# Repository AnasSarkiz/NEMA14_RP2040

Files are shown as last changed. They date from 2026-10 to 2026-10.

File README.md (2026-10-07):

# NEMA14_RP2040

Separate RP2040 hardware prototype derived from the CH32X035 NEMA14 controller. This project has its own source, routing and package identity; it does not replace the CH32 project.

[GitHub](https://github.com/AnasSarkiz/NEMA14_RP2040) · [tscircuit](https://tscircuit.com/AnasSarkiz/NEMA14_RP2040)

For STEPperONLINE **14HM11-0404S**: 0.9° bipolar motor, 0.40 A/phase, 25 Ω windings, 35.2 mm maximum body width. The 35 × 35 mm four-layer PCB has four 3.2 mm holes at 26 mm pitch. The manufacturer specifies those dimensions for **front** mounting only; rear attachment uses an adapter and remains physically unverified.

- Two top-side USB-C receptacles, openings flush at opposite board edges: CH224K PD sink requests 15 V, separate USB 2.0 data connection to RP2040.
- RP2040 QFN56, 2 MB GD25Q16EEIGR external QSPI flash, 12 MHz ABM8-272-T3 crystal, 27 Ω USB resistors, all supply bypasses and 1.1 V core-regulator reservoirs.
- AP63203WU-7 3.3 V buck, diode-OR inputs from PD and data VBUS. Motor rail is supplied only by the PD port; data VBUS cannot supply the motor.
- A4988 chopper driver: 1/16 stepping, nominal peak phase-current setting 0.351 A. This setting uses 39k/10k VREF and 0.24 Ω sense resistors; 1% divider/sense resistors and the regulator tolerance must be included in the production current review.
- Top-side component assembly; top/inner2/bottom routing, inner1 ground plane and through-vias. The four-layer PCB costs more than the CH32 two-layer version. SWD/reset solder pads, BOOTSEL solder pads (short to GND while resetting), four motor wire solder holes. These pads avoid connector/button cost.

Motor connection: black A+, green A−, red B+, blue B−. Firmware must keep ENABLE_N high and SLEEP low until the negotiated supply is verified. Data-VBUS sensing is required to disconnect the USB device pull-up when the host cable is absent.

```sh
npm ci --legacy-peer-deps
npm run typecheck
npm run source:check
npm run autoroute       # diagnostic copper saved separately
npm run build           # render/check delivery copper, without rerouting
npm run export
npm run shorts
```

See [routing](docs/routing.md), [electrical review](docs/electrical.md), and [firmware interface](docs/firmware-interface.md). **Hardware prototype, not a fabrication release.** No firmware or bench-tested USB, PD, current or thermal behavior is included.

Saved validation: 0 DRC errors, 48 nets connected and no Gerber shorts detected across all four copper layers. Power/ground pin metadata and passive connector/crystal classifications are explicit; current DRC reports zero warnings. [BOM](artifacts/bom.csv), [Gerbers](artifacts/nema14-gerbers.zip) and [top preview](artifacts/pcb-top.png) are included. Exact passive purchasing identities, assembly rotations and the inductor footprint still require assembly review.

## Supplier models and A4 schematics

[Printable A4 schematic](artifacts/schematic-a4.pdf): 13 numbered landscape sheets with chip-purpose notes and every numbered physical pin. All **61/61 fitted components** use exact JLCPCB imports with native land patterns and OBJ/STEP models. Motor/debug/boot connections are bare PCB pads. See [supplier CAD details](docs/supplier-cad.md) and [the import report](artifacts/jlcpcb-import-report.json).

## USB and final validation

[USB programming procedure](docs/usb-programming.md) · [Validation details](docs/validation.md) · [Browser schematic analysis](artifacts/validation/schematic-analysis-ui.png). Both board variants support boot-mode entry through their Data USB-C port; flashing still requires assembled-hardware validation. Current software checks report zero DRC errors/warnings, zero schematic-placement findings and no Gerber shorts. Application firmware remains a separate task.

The public main entry point is `index.circuit.tsx`, which exports the board from `src/board.tsx`. `index.circuit.json` is the checked saved layout; publication refreshes it from `artifacts/board.circuit.json` and includes both JSON files. `tscircuit.config.json` selects the root source entry and saved-layout preview.

Publication uses the CLI build-output option: `tsci push index.circuit.tsx --include-dist`. Before uploading, the script runs `tsci build index.circuit.json` and verifies that `dist/index/circuit.json` equals the checked saved routing.

## Copper and electrical review

The [electrical review](docs/electrical.md) records power-trace widening, filled grounds, the corrected 100 kΩ/10 kΩ motor-voltage divider, copper-thickness requirements, and remaining prototype tests. Run `npm run check:copper` for the actual saved-segment audit. The [machine-readable report](artifacts/trace-width-review.json) distinguishes isolated tracks from parallel ground-plane paths; software checks do not certify hardware operation.

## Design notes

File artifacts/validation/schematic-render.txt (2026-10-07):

> NEMA14_RP2040@1.0.8 render
> bun scripts/render.ts --schematic-only

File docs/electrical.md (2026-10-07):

# Electrical design review

RP2040 is not a drop-in CH32 replacement. All six IOVDD pins, USB_VDD, ADC_AVDD and VREG_IN use 3.3 V. VREG_OUT and both DVDD pins use the separate internal 1.1 V rail. Each IOVDD/DVDD/USB/ADC supply has a 100 nF bypass; VREG input/output each have 1 μF. TESTEN and the exposed pad are grounded. RUN has a 10k pull-up and a debug reset pad.

12 MHz ABM8-272-T3 has 10 pF specified load; two 15 pF capacitors assume about 2.5 pF parasitic load. A 1k XOUT series damping resistor is included. Verify clock startup and drive level on hardware. GD25Q16EEIGR is 16 Mbit/2 MB, 3.3 V USON8. Flash CS has 10k pull-up; both IO2/IO3 are wired to RP2040 for quad mode.

AP63203WU-7 pin map checked against DS41326 Rev 3-2: FB1, EN2, VIN3, GND4, SW5, BST6. Fixed 3.3 V output, 3.8–32 V input, 1.1 MHz. Manufacturer table 2 specifies 3.9 μH, 10 μF input, two 22 μF output and 100 nF bootstrap. This prototype uses a 4.7 μH SRN4018-4R7M, a nearby standard value reducing ripple; verify stability and load-step behavior. FB senses the output directly. Input ceramic must be rated ≥35 V; bootstrap ≥25 V; output ceramics ≥10 V and retain sufficient capacitance after bias. Inductor saturation/ripple-current and exact footprint require purchasing review. Do not populate an adjustable AP63200 in this footprint without changing the feedback network.

Diode ORing keeps PD voltage out of host VBUS. Actual 5 V USB minimum, Schottky drop and buck dropout must be verified. CH224K supplies motor VBUS only; fallback 5 V cannot run the A4988. PG and VM ADC voltage gate firmware enable. 15 V is requested, not guaranteed with every charger/cable.

A4988 VREF = 3.3 × 10/(39+10) = 0.6735 V; Itrip = VREF/(8 × 0.24) = 0.3508 A. The native 0.24 Ω, 1%, 125 mW resistors dissipate about 29.5 mW nominally. A deliberately expanded 3.465 V rail budget, 1% resistor bounds and a provisional 5% driver allowance estimate 0.3969 A. This is an engineering budget, not a qualified maximum: the actual driver accuracy, ground bounce and sense-track resistance must be measured. The SMF18A clamp still requires regenerative-energy testing.

Only exposed-pad ground vias may sit inside component pads; ordinary vias must clear pads. Component assembly is on top; PCB uses four copper layers: top / inner1 ground / inner2 signals / bottom. Ground is filled on all layers, with inner1 reserved from signal routing. USB is full-speed 12 Mbit/s: matched short pair and continuous ground reference require layout review beyond a generic DRC/short test. No controlled-impedance or EMC compliance claim is made.

## Copper review, 2026-10-07

The checked saved layout, rather than nominal JSX settings, was reviewed. Power/motor tracks were widened only when exact imported pad, via and foreign-track geometry retained at least 0.15 mm clearance. Their centerlines were retained. `artifacts/power-copper-adjustments.json` records each width change; `supplier-routing-adjustments.json` replays the complete result from the saved SES import. Ground pours have 0.20 mm clearance, 0.35 mm edge margin, and no unconnected islands. Components remain top-side assembled.

| Copper | Actual saved width / review |
| --- | --- |
| Motor outputs / sense | About 0.28–0.45 mm, including package escapes; screened at 0.40 A peak |
| PD motor supply | 0.30–0.60 mm; 0.75 A input budget, with a verified single-bridge RP2040 branch screened at 0.40 A |
| Logic supply / switching node | Widened where possible; package escapes remain as small as 0.16 mm; 0.15 A rail / 0.20 A switching budget |
| Ground | 0.16–0.45 mm tracks plus filled ground copper; parallel plane paths must be considered, rather than assuming the entire motor return flows down every ground stub |
| USB / other signals | 0.16 mm; width alone does not establish differential impedance or signal integrity |

Copper screening requires **at least 35 μm finished external copper and 17.5 μm internal copper** where applicable, on 1.6 mm FR-4, with at least 20 μm via barrel plating. These are fabrication requirements, not measurements of a manufactured PCB. IPC-2221 equations use k=0.048 externally and 0.024 internally, with a 30 °C rise screening limit. The report includes each actual segment, layer, current budget and temperature estimate. This approximate method does not model enclosure/motor heating, neck heat spreading, switching pulses, vias or ground-plane current sharing.

The largest isolated non-ground trace estimate is 25.2 °C at its assigned budget. Ground traces covered by the same-net pour are explicitly reported as parallel paths; their isolated-track estimate is not a prediction of actual plane temperature. Ground current sharing and regulator/driver temperatures remain bench checks.

## Voltage sensing correction

R_VM_H/R_VM_L is now **100 kΩ/10 kΩ**, replacing 100 kΩ/22 kΩ. It produces 1.364 V at 15 V; the worst resistor-tolerance value is 3.240 V at a 35 V review envelope. The old divider produced 3.606 V at only 20 V, before tolerance, so motor regeneration could overstress the ADC input. This change reuses JLCPCB C25804 and its unchanged native footprint. **Firmware must multiply VM_SENSE voltage by 11**, with calibration as needed. The 35 V arithmetic envelope is not approval to operate the motor bus at 35 V; the intended supply remains 15 V. Rails, TVS energy and component ratings require transient testing.

## Operation review and remaining tests

CH224K requests 15 V with CFG1/2/3 = 0/1/1; PG is active low. A supply must advertise the requested PDO. Driver ENABLE_N has a pull-up, SLEEP has a pull-down, and firmware must keep the bridge disabled until PG and measured VM are valid. Diode ORing separates host VBUS from PD while permitting logic-only USB power. USB/data ground is shared with motor power.

USB programming entry is wired: WCH ROM ISP through PC17/D+ at cold power-up on CH32; RP2040 ROM USB boot through the flash-CS boot jumper and RUN/reset. This has not been demonstrated on physical hardware. USB routes were checked for continuity and shorts, but were not impedance-qualified or accepted as a length-matched differential pair. Reported per-net copper totals contain connector/ESD branches and must not be interpreted as pair skew. Host-only, PD-only and simultaneous-cable tests, both Type-C orientations, repeated enumeration and actual flashing are required.

At first bring-up, keep the motor disconnected, power through a current-limited source, check all rails and confirm disabled outputs. Then verify 15 V PD negotiation/fallback behavior and absence of host backfeed. Measure 3.3 V ripple and load-step response (plus RP2040 1.1 V and crystal startup), flash over USB, measure both phase currents and sense offsets, and exercise stalled/accelerating/stopping motor cases while watching VM overshoot and driver/regulator temperatures. Test at the intended motor/enclosure temperature. The CH32 linear regulator dissipates roughly (14.6−3.3)×I_logic, or about 0.34 W at 30 mA; the 100 mA part rating alone is not a thermal guarantee. The RP2040 buck's switching/input loop and feedback placement require ripple/stability validation.

No motor-control firmware is present. Rear mounting remains unverified because the motor drawing dimensions only the front face. Manufacturer-level A4988 accuracy, CH224K/HT7533 electrical limits and component transient ratings remain purchasing/release checks; direct manufacturer document retrieval was blocked in this environment. Existing pin/reference and supplier evidence is recorded in `docs/sources.md`. **Manufacturing release remains blocked.**

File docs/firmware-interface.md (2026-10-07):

# RP2040 firmware contract

Use the Pico SDK RP2040 target with 12 MHz XOSC and 2 MB flash. Select the generic JEDEC-compatible boot stage for GD25Q16E; do not assume a Winbond-specific quad-enable sequence. Flash boot and UF2 USB ROM boot require hardware validation.

| Function | RP2040 GPIO / physical pin |
| --- | --- |
| STEP | GPIO6 / 8 |
| DIR | GPIO7 / 9 |
| ENABLE_N | GPIO8 / 11 |
| SLEEP | GPIO9 / 12 |
| PD_GOOD (active low) | GPIO10 / 13 |
| VM_SENSE | ADC2 / GPIO28 / 40 |
| DATA_PRESENT | ADC3 / GPIO29 / 41 |
| SWCLK / SWDIO | 24 / 25 |
| RUN | 26 |
| USB DM / DP | 46 / 47, through 27 Ω resistors |

On reset, pull-ups/pull-downs disable the A4988. Initialize outputs disabled; require PG and measured VM within an accepted 15 V window, then wake the driver and respect its timing before enabling. Monitor supply loss and shut down immediately. Keep USB pull-up disconnected without DATA_PRESENT. Start with low speed; the 24 mH motor inductance and actual torque/load set speed limits.

Full steps: 400/revolution. Configured 1/16 microsteps: 6400/revolution. No USB protocol/application firmware is implemented.

J_DEBUG bottom-to-top in the top PCB view: 3V3, GND, SWCLK, SWDIO, RUN. J_BOOT shorts flash CS to GND through 1 kΩ: hold short while asserting/releasing RUN to enter ROM USB boot. Never leave the short during ordinary flash operation.

For factory ROM USB boot entry, see [USB programming](usb-programming.md). This hardware contract does not supply a motor-control application.

Motor voltage conversion: `VM_V = VM_SENSE_V × 11` for the reviewed 100 kΩ/10 kΩ divider. Update/calibrate firmware accordingly; the former ×(122/22) conversion is obsolete.

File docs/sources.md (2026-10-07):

# Sources and provenance

- Original CH32 project: `AnasSarkiz/NEMA17_Controller`, commit `e19f75e` (independently copied source; original project remains unchanged).
- tscircuit 0.0.2759, CLI 0.1.2258: latest npm releases checked during this change, pinned in lockfile.
- RP2040 Raspberry Pi manufacturer datasheet (cached official supplier copy): `references/RP2040.pdf`. Sections 1.4 and 2.9 establish the numbered pin map, power rails, bypasses, 12 MHz USB boot clock and 27 Ω USB resistors. Original https://datasheets.raspberrypi.com/rp2040/rp2040-datasheet.pdf . Direct manufacturer website access is blocked in this environment; the cached PDF was read.
- Diodes AP63203 DS41326 Rev 3-2, November 2024: `references/AP63203.pdf`, pin descriptions, component table 2 and PCB layout guidance. https://www.diodes.com/assets/Datasheets/AP63200-AP63201-AP63203-AP63205.pdf . Cached manufacturer PDF was read.
- Abracon ABM8-272-T3, drawing 456603 Rev IR November 2023: `references/ABM8-272-T3.pdf`, 12 MHz / 10 pF load / 50 Ω ESR.
- GigaDevice GD25Q16E Rev 1.5: `references/GD25Q16E.pdf`, 16 Mbit, USON 3×2 mm, flash pins and quad-enable behavior. Device-specific boot support requires testing.
- STEPperONLINE 14HM11-0404S: `references/14HM11-0404S.pdf`, retrieved from https://www.omc-stepperonline.com/download/14HM11-0404S.pdf . Electrical ratings and front 26 ±0.2 mm M3 pitch confirmed; rear hole dimensions absent.
- RP2040, AP63203, GD25Q16EEIGR and crystal pad geometry copied from existing cached supplier imports. Numbered pins checked against manufacturer references; assembly/library review is still needed. No generic QFN footprint is substituted for the reduced RP2040 ground pad.

The remaining A4988, CH224K, USB-C and ESD footprints derive from the original project. This is an engineering prototype; exact purchasing identities for passives and the inductor land pattern require final assembly review. No stock check or assembly quote is claimed.

Current fitted parts are genuine JLCPCB imports obtained with `tsci import --jlcpcb --download --use-exact-footprint <C-number>`. `src/jlcpcb-catalog.json` records component-to-part mapping, original import hashes and native OBJ/STEP hashes. No fitted part uses a custom replacement footprint. Earlier KiCad/Eagle references establish pin cross-checks only; they do not define the current supplier land patterns.

Current tools: tscircuit 0.0.2764, CLI 0.1.2261, pinned in the lockfile. WCH evaluation-board reference section 5 documents PC17-high cold-start ROM USB programming. RP2040 and AP63203 manufacturer PDFs used for power/boot/reference checks are cached in the RP2040 project's `references/` directory. The AP63203 PDF is DS41326 Rev 3-2, November 2024, including the fixed-output pin map and PCB layout guidance. Additional direct Allegro/Raspberry Pi document retrieval during this review returned HTTP 403; no new manufacturer qualification is claimed from those failed requests.

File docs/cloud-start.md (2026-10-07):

# Cloud startup

Use the existing `/workspace/NEMA17_Controller` and `/workspace/NEMA14_RP2040` checkouts. Install from lockfiles using `npm ci --legacy-peer-deps`; local scripts supply Bun. `scripts/cloud-install.sh` restores Python routing dependencies in `/workspace/.routing-venv`, verifies locked Git dependency source checksums and Freerouting 2.0.1. Retain TLS/checksum checks.

Run TypeScript, source compilation, saved-board build, native physical connectivity and all-layer Gerber shorts checks. The delivery has 351 trace sections/38 fitted supplier models on CH32 and 519 trace sections/61 fitted models on RP2040; DRC errors and warnings are zero. `npm run build` uses saved copper. `npm run autoroute` writes a separate diagnostic result and does not replace delivery copper.

Use `XDG_CONFIG_HOME=/workspace/.config` for authenticated CLI publication. Reuse configured authentication without printing secrets. Exact JLCPCB imports and OBJ/STEP assets are in `imports/supplier/`; CAD viewers load public GitHub URLs. Native A4 drawings have 9 CH32 and 13 RP2040 pages. The supplier report requires the routing Python environment: `/workspace/.routing-venv/bin/python scripts/report-presentation.py`.

`npm run dev -- --port 5173` starts the saved-board preview. `python3 scripts/schematic-review-ui.py` starts the read-only native A4/CLI findings review UI. Check local HTTP endpoints internally; share the public project links. The official IDE saved-JSON schematic pane is disabled and WebGPU is unavailable here. Restart servers in a fresh task.

Both designs remain unassembled prototypes. Rear-motor fit, physical USB flashing, PD/thermal testing and firmware implementation remain outstanding. The manufacturer drawing gives front mounting only; four 26 mm-pitch holes are for an unverified rear adapter. The CH32 GitHub identity remains AnasSarkiz/NEMA17_Controller because its requested rename returned HTTP 403. Environment draft saving does not activate its configuration; review/save/publish in environment settings. Fresh-task restoration has not been independently tested.

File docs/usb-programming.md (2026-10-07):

# USB programming

1. Short the two bare `J_BOOT` pads to hold flash chip-select low through `R_BOOT` (1 kΩ).
2. While holding the short, connect the computer to **J_DATA** from a fully unpowered board, or momentarily pull `J_DEBUG.RUN` to GND to reset the powered MCU.
3. Release `J_BOOT` after the ROM enters USB boot mode.
4. Copy a firmware UF2 built for this RP2040 board to the ROM's `RPI-RP2` drive, or use `picotool`.

Source: [RP2040 datasheet](https://datasheets.raspberrypi.com/rp2040/rp2040-datasheet.pdf), boot sequence and USB boot documentation. The QSPI flash, 12 MHz crystal, USB 27 Ω series resistors and required rails are present. There is no fitted BOOT button; use the exposed pads. SWD and RUN remain available on `J_DEBUG`.

The **PD port is motor power only**, requesting 15 V. Programming uses the separate **Data USB-C port**. USB ROM entry connections and physical copper continuity have been checked in CAD. Enumeration, boot-ROM PHY operation at the chosen supply, and actual flashing must still be tested on an assembled prototype. No motor-control firmware has been implemented or preloaded. Keep the motor disconnected during the first flashing/rail checks.

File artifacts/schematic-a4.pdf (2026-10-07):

A | A

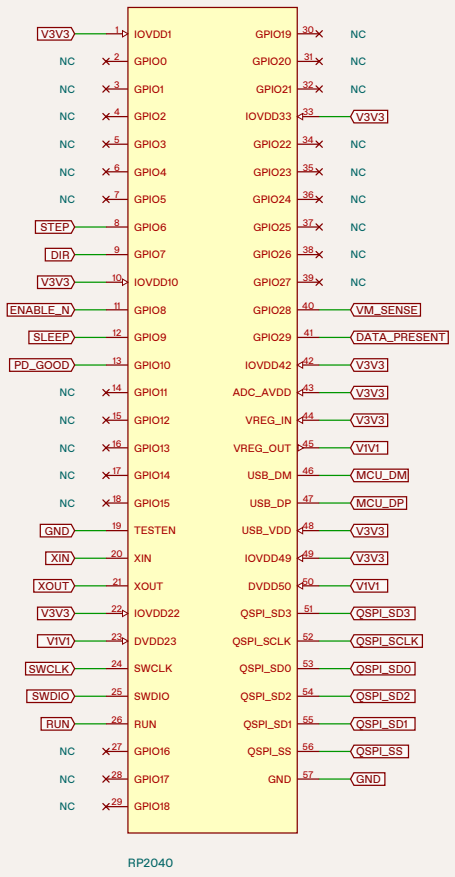
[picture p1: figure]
IOVDD1; GPIO0; GPIO1; GPIO2; GPIO3; GPIO4; GPIO5; GPIO6; GPIO7; 10 IOVDD10; GPIO8; 12 GPIO9; 13 GPIO10; 14 GPIO11; 15 GPIO12; 16 GPIO13; 17 GPIO14; 18 GPIO15; 19 TESTEN; 20 XIN; 21 XOUT; 22 IOVDD22; 23 DVDD23; 24 SWCLK; 25 SWDIO; 26 RUN; 27 GPIO16; 28 GPIO17; 29 GPIO18; 30 GPIO19; 31 GPIO20; 32 GPIO21; 33 IOVDD33; 34 GPIO22; 35 GPIO23; 36 GPIO24; 37 GPIO25; 38 GPIO26; 39 GPIO27; 40 GPIO28; 41 GPIO29; 42 IOVDD42; 43 ADC_AVDD; 44 VREG_IN; 45 VREG_OUT; 46 USB_DM; 47 USB_DP; 48 USB_VDD; 49 IOVDD49; 50 DVDD50; 51 QSPI_SD3; 52 QSPI_SCLK; 53 QSPI_SD0; 54 QSPI_SD2; 55 QSPI_SD1; 56 QSPI_SS; 57 GND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

B | B
C | C
D | D

### U_MCU

## NEMA14_RP2040 - USB-C NEMA14 MOTOR CONTROLLER

## COMPONENT PURPOSE

### U_MCU - RP2040

USB computer control; generates STEP/DIR. Checks PD voltage before enabling the motor. Internal regulator supplies the 1.1 V core.

### U_FLASH - GD25Q16EEIGR

2 MB external QSPI flash stores firmware. Required because RP2040 has no internal flash. BOOT pads permit ROM USB boot recovery.

### Y_MCU - ABM8-272-T3

12 MHz crystal is the USB clock reference. Load capacitors and XOUT resistor support oscillation and limit crystal drive.

### U_PD - CH224K

USB-C PD sink requests a 15 V motor supply. PG reports a completed power negotiation.

### U_BUCK - AP63203WU-7

Efficient 3.3 V supply for MCU and logic. Diode OR accepts USB data power or PD. Inductor and capacitors smooth switching.

### U_DRV - A4988

Two current-regulated bridges drive the coils. STEP/DIR interface; fixed 1/16 microstepping. Nominal phase-current limit is 0.351 A.

### U_ESD - USBLC6-2SC6

Clamps ESD on USB D+ and D- at the data port. VBUS pin references the protection diodes.

PD PORT: motor power, 15 V requested. DATA PORT: USB computer control.
Motor: 14HM11-0404S, bipolar, 0.4 A/phase. Prototype: firmware/bench/rear-fit validation pending.

### SHEET 1/13 - U_MCU

Named nets connect across all pages. NC = intentionally unconnected pin.

A | A

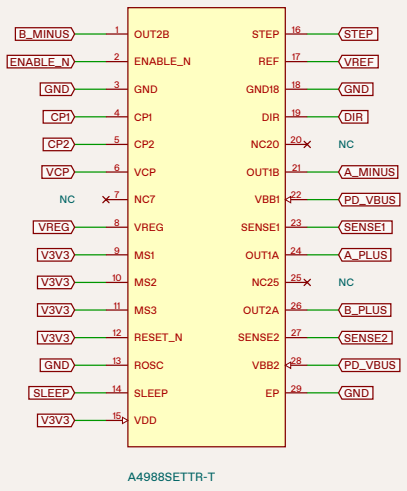
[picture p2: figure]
A4988SETTR-T; OUT2B; ENABLE_N; GND; VCP; VREG; 12 RESET_N; 13 ROSC; 14 SLEEP; 15 VDD; 16 STEP; 17 REF; 18 GND18; 19 DIR; 21 OUT1B; 22 VBB1; 23 SENSE1; 24 OUT1A; 26 OUT2A; 27 SENSE2; 28 VBB2; B_MINUS; SLEEP; STEP; VREF; DIR; A_MINUS; PD_VBUS; SENSE1; A_PLUS; B_PLUS; SENSE2

B | B
C | C
D | D

### U_DRV

## COMPONENT PURPOSE

### U_MCU - RP2040

USB computer control; generates STEP/DIR. Checks PD voltage before enabling the motor. Internal regulator supplies the 1.1 V core.

### U_FLASH - GD25Q16EEIGR

2 MB external QSPI flash stores firmware. Required because RP2040 has no internal flash. BOOT pads permit ROM USB boot recovery.

### Y_MCU - ABM8-272-T3

12 MHz crystal is the USB clock reference. Load capacitors and XOUT resistor support oscillation and limit crystal drive.

### U_PD - CH224K

USB-C PD sink requests a 15 V motor supply. PG reports a completed power negotiation.

### U_BUCK - AP63203WU-7

Efficient 3.3 V supply for MCU and logic. Diode OR accepts USB data power or PD. Inductor and capacitors smooth switching.

### U_DRV - A4988

Two current-regulated bridges drive the coils. STEP/DIR interface; fixed 1/16 microstepping. Nominal phase-current limit is 0.351 A.

### U_ESD - USBLC6-2SC6

Clamps ESD on USB D+ and D- at the data port. VBUS pin references the protection diodes.

PD PORT: motor power, 15 V requested. DATA PORT: USB computer control.
Motor: 14HM11-0404S, bipolar, 0.4 A/phase. Prototype: firmware/bench/rear-fit validation pending.

### SHEET 2/13 - U_DRV

Named nets connect across all pages. NC = intentionally unconnected pin.

A | A
B | B
C | C
D | D

### J_PD

TYPE-C-31-M-12

NC

NC

NC

NC

NC

NC

1 | EH2
2 | EH1
3 | EH4
4 | EH3
5 | SBU2
6 | CC1
7 | DN2
8 | DP1

9 DN1

10 DP2

11 SBU1

12 CC2

13 GND1

14 GND2

15 VBUS1

16 VBUS2

### J_DATA

TYPE-C-31-M-12

NC

NC

1 | EH2
2 | EH1
3 | EH4
4 | EH3
5 | SBU2
6 | CC1
7 | DN2
8 | DP1

9 DN1

10 DP2

11 SBU1

12 CC2

13 GND1

14 GND2

15 VBUS1

16 VBUS2

### U_PD

CH224K

NC

NC

1 | VDD
2 | CFG2
3 | CFG3
4 | DP
5 | DM
6 | CC2

7 CC1

8 VBUS

9 CFG1

10 PG

11 GND

R_PD
1kΩ

C_PD

1uF

R_PG
10kΩ

GND

GND

GND

GND

PD_CC1

PD_CC2

GND

GND

PD_VBUS

PD_VBUS

GND

GND

GND

GND

DATA_CC1

USB_DM

USB_DP

USB_DM

USB_DP

DATA_CC2

GND

GND

DATA_VBUS

DATA_VBUS

PD_VDD

PD_VDD

PD_VDD

PD_CC2

PD_CC1

PD_VBUS

GND

PD_GOOD

GND

PD_VBUS PD_VDD

PD_VDD GND
V3V3 PD_GOOD

## COMPONENT PURPOSE

### U_MCU - RP2040

USB computer control; generates STEP/DIR. Checks PD voltage before enabling the motor. Internal regulator supplies the 1.1 V core.

### U_FLASH - GD25Q16EEIGR

2 MB external QSPI flash stores firmware. Required because RP2040 has no internal flash. BOOT pads permit ROM USB boot recovery.

### Y_MCU - ABM8-272-T3

12 MHz crystal is the USB clock reference. Load capacitors and XOUT resistor support oscillation and limit crystal drive.

### U_PD - CH224K

USB-C PD sink requests a 15 V motor supply. PG reports a completed power negotiation.

### U_BUCK - AP63203WU-7

Efficient 3.3 V supply for MCU and logic. Diode OR accepts USB data power or PD. Inductor and capacitors smooth switching.

### U_DRV - A4988

Two current-regulated bridges drive the coils. STEP/DIR interface; fixed 1/16 microstepping. Nominal phase-current limit is 0.351 A.

### U_ESD - USBLC6-2SC6

Clamps ESD on USB D+ and D- at the data port. VBUS pin references the protection diodes.

PD PORT: motor power, 15 V requested. DATA PORT: USB computer control.
Motor: 14HM11-0404S, bipolar, 0.4 A/phase. Prototype: firmware/bench/rear-fit validation pending.

### SHEET 3/13 - J_PD, J_DATA, U_PD, R_PD, C_PD, R_PG

Named nets connect across all pages. NC = intentionally unconnected pin.

A | A
B | B
C | C
D | D

C_IO1

100nF

C_IO10

100nF

C_IO22

100nF

C_IO33

100nF

C_IO42

100nF

C_IO49

100nF

V3V3 GND

V3V3 GND

V3V3 GND

V3V3 GND

V3V3 GND

V3V3 GND

## COMPONENT PURPOSE

### U_MCU - RP2040

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

### U_FLASH - GD25Q16EEIGR

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

### Y_MCU - ABM8-272-T3

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

### U_PD - CH224K

USB-C PD sink requests a 15 V motor supply. PG reports a completed power negotiation.

### U_BUCK - AP63203WU-7

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

### U_DRV - A4988

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

### U_ESD - USBLC6-2SC6

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

### SHEET 4/13 - C_IO1, C_IO10, C_IO22, C_IO33, C_IO42, C_IO49

Named nets connect across all pages. NC = intentionally unconnected pin.

A | A
B | B
C | C
D | D

C_DV23

100nF

C_DV50

100nF

C_USB

100nF

C_ADC

100nF

C_VREG_IN

1uF

C_VREG_OUT

1uF

V1V1 GND

V1V1 GND

V3V3 GND

V3V3 GND

V3V3 GND V1V1 GND

## COMPONENT PURPOSE

### U_MCU - RP2040

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

### U_FLASH - GD25Q16EEIGR

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

### Y_MCU - ABM8-272-T3

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

### U_PD - CH224K

USB-C PD sink requests a 15 V motor supply. PG reports a completed power negotiation.

### U_BUCK - AP63203WU-7

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

### U_DRV - A4988

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

### U_ESD - USBLC6-2SC6

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

### SHEET 5/13 - C_DV23, C_DV50, C_USB, C_ADC, C_VREG_IN, C_VREG_OUT

Named nets connect across all pages. NC = intentionally unconnected pin.

A | A
B | B
C | C
D | D

### U_FLASH

GD25Q16EEIGR

1 | CS
2 | IO1
3 | IO2
4 | GND
5 | IO0

6 CLK

7 IO3

8 VCC

9 EP

C_FLASH

100nF

R_FLASH_CS
10kΩ

R_BOOT

1kΩ

### J_BOOT

PCB solder interface

### 1 BOOT 2 GND

### Y_MCU

ABM8-272-T3

QSPI_SS

QSPI_SD1

QSPI_SD2

GND

QSPI_SD0

QSPI_SCLK

QSPI_SD3

V3V3

GND

V3V3 GND

V3V3 QSPI_SS

QSPI_SS | BOOT_PAD

BOOT_PAD GND

XIN

GND

XTAL_OUT

GND

## COMPONENT PURPOSE

### U_MCU - RP2040

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

### U_FLASH - GD25Q16EEIGR

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

### Y_MCU - ABM8-272-T3

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

### U_PD - CH224K

USB-C PD sink requests a 15 V motor supply. PG reports a completed power negotiation.

### U_BUCK - AP63203WU-7

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

### U_DRV - A4988

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

### U_ESD - USBLC6-2SC6

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

### SHEET 6/13 - U_FLASH, C_FLASH, R_FLASH_CS, R_BOOT, J_BOOT, Y_MCU

Named nets connect across all pages. NC = intentionally unconnected pin.

A | A
B | B
C | C
D | D

R_XOUT

1kΩ

C_XIN

15pF

C_XOUT

15pF

R_RUN
10kΩ

R_DM

27Ω

R_DP

27Ω

XOUT | XTAL_OUT

XIN GND

XTAL_OUT GND

V3V3 RUN

MCU_DM | USB_DM
MCU_DP | USB_DP

## COMPONENT PURPOSE

### U_MCU - RP2040

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

### U_FLASH - GD25Q16EEIGR

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

### Y_MCU - ABM8-272-T3

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

### U_PD - CH224K

USB-C PD sink requests a 15 V motor supply. PG reports a completed power negotiation.

### U_BUCK - AP63203WU-7

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

### U_DRV - A4988

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

### U_ESD - USBLC6-2SC6

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

### SHEET 7/13 - R_XOUT, C_XIN, C_XOUT, R_RUN, R_DM, R_DP

Named nets connect across all pages. NC = intentionally unconnected pin.

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
R_CC1
5.1k

Ω

R_CC2
5.1k

Ω

R_USB_SENSE_H
100k

Ω

R_USB_SENSE_L
100k

Ω

R_VM_H
100k

Ω

R_VM_L
10k

Ω

DATA_CC1 GND

DATA_CC2 GND

DATA_VBUS DATA_PRESENT

DATA_PRESENT GND

PD_VBUS VM_SENSE

VM_SENSE GND

## COMPONENT PURPOSE

### U_MCU - RP2040

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

### U_FLASH - GD25Q16EEIGR

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

### Y_MCU - ABM8-272-T3

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

### U_PD - CH224K

USB-C PD sink requests a 15 V motor supply. PG reports a completed power negotiation.

### U_BUCK - AP63203WU-7

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

### U_DRV - A4988

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

### U_ESD - USBLC6-2SC6

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

### SHEET 8/13 - R_CC1, R_CC2, R_USB_SENSE_H, R_USB_SENSE_L, R_VM_H, R_VM_L

Named nets connect across all pages. NC = intentionally unconnected pin.

A | A
B | B
C | C
D | D

C_VM_SENSE

10nF

### U_BUCK

AP63203WU-7

1 | FB
2 | EN
3 | VIN

4 GND

5 SW

6 BST

L_BUCK 4.7µH

C_BOOTSTRAP

100nF

C_BUCK_IN

10uF

C_BUCK_OUT1

22uF

VM_SENSE GND

V3V3

LOGIC_IN

LOGIC_IN

GND

BUCK_SW

BUCK_BST

BUCK_SW V3V3

BUCK_BST | BUCK_SW

LOGIC_IN GND

V3V3 GND

## COMPONENT PURPOSE

### U_MCU - RP2040

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

### U_FLASH - GD25Q16EEIGR

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

### Y_MCU - ABM8-272-T3

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

### U_PD - CH224K

USB-C PD sink requests a 15 V motor supply. PG reports a completed power negotiation.

### U_BUCK - AP63203WU-7

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

### U_DRV - A4988

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

### U_ESD - USBLC6-2SC6

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

### SHEET 9/13 - C_VM_SENSE, U_BUCK, L_BUCK, C_BOOTSTRAP, C_BUCK_IN, C_BUCK_OUT1

Named nets connect across all pages. NC = intentionally unconnected pin.

A | A
B | B
C | C
D | D

C_BUCK_OUT2

22uF

D_PD

D_DATA | C_CP
| 100nF

C_VCP

100nF

C_VREG

220nF

V3V3 GND

PD_VBUS | LOGIC_IN
DATA_VBUS | LOGIC_IN | CP1 | CP2 VCP PD_VBUS | VREG GND

## COMPONENT PURPOSE

### U_MCU - RP2040

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

### U_FLASH - GD25Q16EEIGR

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

### Y_MCU - ABM8-272-T3

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

### U_PD - CH224K

USB-C PD sink requests a 15 V motor supply. PG reports a completed power negotiation.

### U_BUCK - AP63203WU-7

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

### U_DRV - A4988

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

### U_ESD - USBLC6-2SC6

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

### SHEET 10/13 - C_BUCK_OUT2, D_PD, D_DATA, C_CP, C_VCP, C_VREG

Named nets connect across all pages. NC = intentionally unconnected pin.

A | A
B | B
C | C
D | D

C_DRV_LOGIC

100nF

C_VM

100nF

C_BULK

47uF

R_SA
240mΩ

R_SB
240mΩ

R_REF_H
39kΩ

V3V3 GND

PD_VBUS GND

PD_VBUS GND

SENSE1 GND

SENSE2 GND
V3V3 VREF

## COMPONENT PURPOSE

### U_MCU - RP2040

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

### U_FLASH - GD25Q16EEIGR

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

### Y_MCU - ABM8-272-T3

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

### U_PD - CH224K

USB-C PD sink requests a 15 V motor supply. PG reports a completed power negotiation.

### U_BUCK - AP63203WU-7

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

### U_DRV - A4988

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

### U_ESD - USBLC6-2SC6

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

### SHEET 11/13 - C_DRV_LOGIC, C_VM, C_BULK, R_SA, R_SB, R_REF_H

Named nets connect across all pages. NC = intentionally unconnected pin.

A | A
B | B
C | C
D | D

R_REF_L
10kΩ

C_REF

10nF

R_ENABLE
100kΩ

R_SLEEP
100kΩ

### J_MOTOR

PCB solder interface

1 | A_PLUS
2 | A_MINUS

3 B_PLUS

4 B_MINUS

### J_DEBUG

PCB solder interface

1 | VDD
2 | GND
3 | SWCLK

4 SWDIO

5 RUN

VREF GND

VREF GND

V3V3 ENABLE_N

SLEEP GND

A_PLUS

A_MINUS

B_PLUS

B_MINUS

V3V3

GND

SWCLK

SWDIO

RUN

## COMPONENT PURPOSE

### U_MCU - RP2040

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

### U_FLASH - GD25Q16EEIGR

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

### Y_MCU - ABM8-272-T3

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

### U_PD - CH224K

USB-C PD sink requests a 15 V motor supply. PG reports a completed power negotiation.

### U_BUCK - AP63203WU-7

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

### U_DRV - A4988

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

### U_ESD - USBLC6-2SC6

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

### SHEET 12/13 - R_REF_L, C_REF, R_ENABLE, R_SLEEP, J_MOTOR, J_DEBUG

Named nets connect across all pages. NC = intentionally unconnected pin.

A | A
B | B
C | C
D | D

### U_ESD

USBLC6-2SC6

1 | DP1
2 | GND
3 | DM1

4 DM2

5 VBUS

6 DP2

### D_TVS

SMF18A

USB_DP

GND

USB_DM

USB_DM

DATA_VBUS

USB_DP

GND PD_VBUS

## COMPONENT PURPOSE

### U_MCU - RP2040

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

### U_FLASH - GD25Q16EEIGR

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

### Y_MCU - ABM8-272-T3

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

### U_PD - CH224K

USB-C PD sink requests a 15 V motor supply. PG reports a completed power negotiation.

### U_BUCK - AP63203WU-7

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

### U_DRV - A4988

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

### U_ESD - USBLC6-2SC6

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

### SHEET 13/13 - U_ESD, D_TVS

Named nets connect across all pages. NC = intentionally unconnected pin.

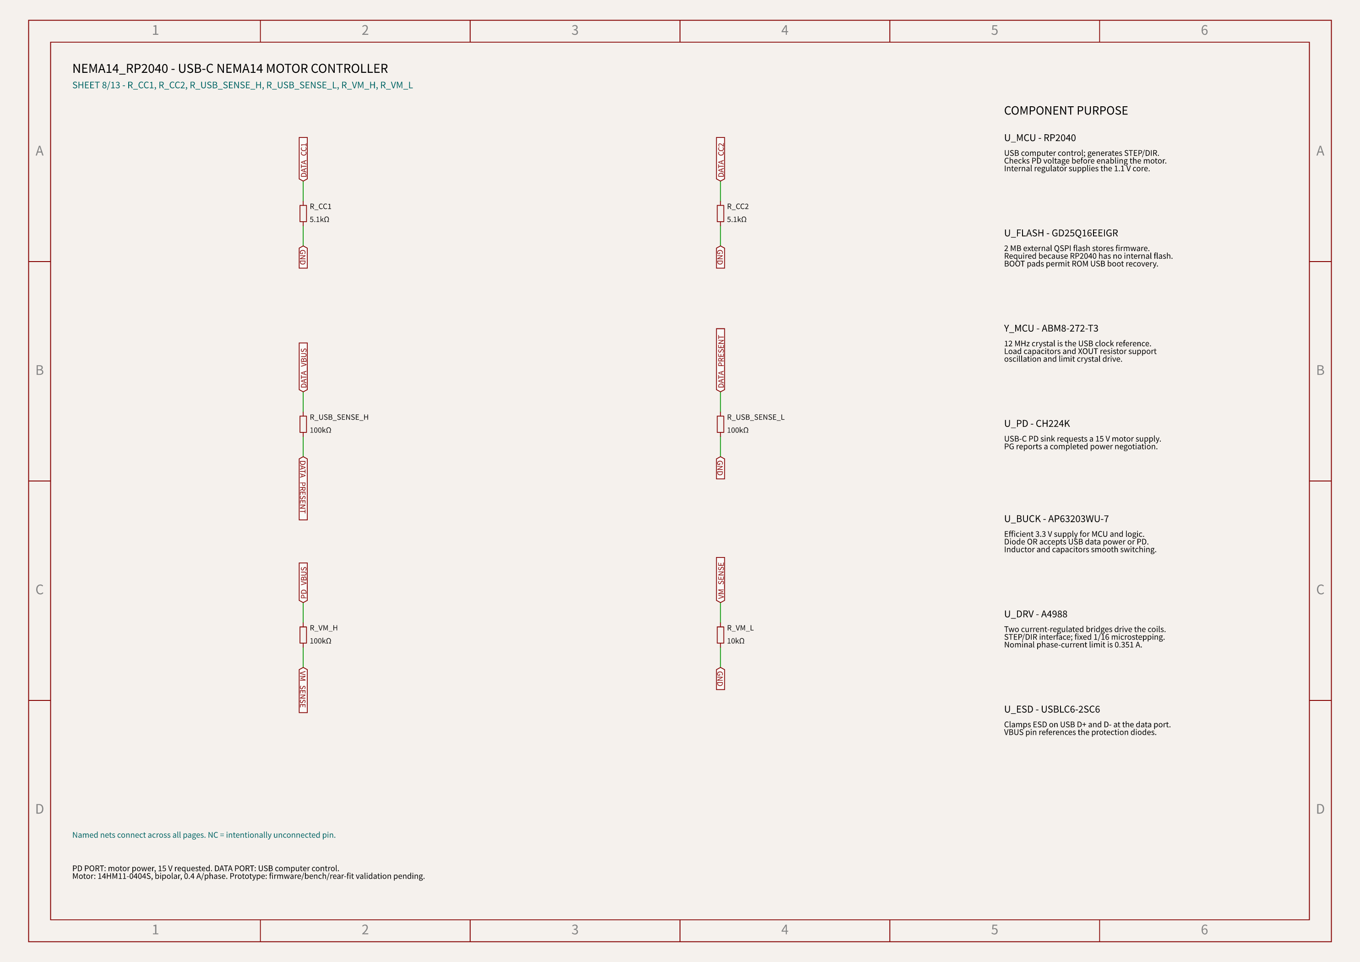
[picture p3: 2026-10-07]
artifacts/schematic-a4-page-08.png

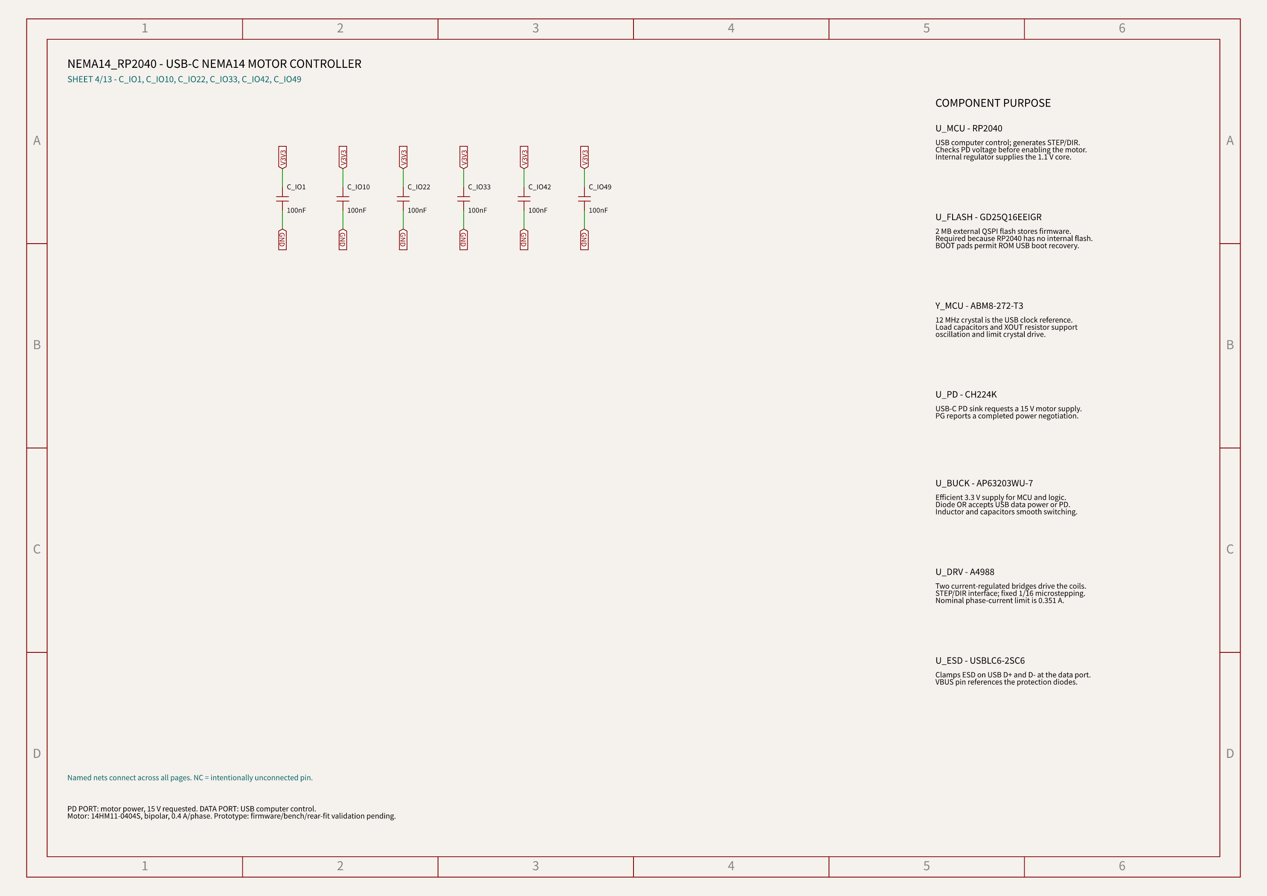
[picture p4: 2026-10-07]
artifacts/schematic-a4-page-04.png

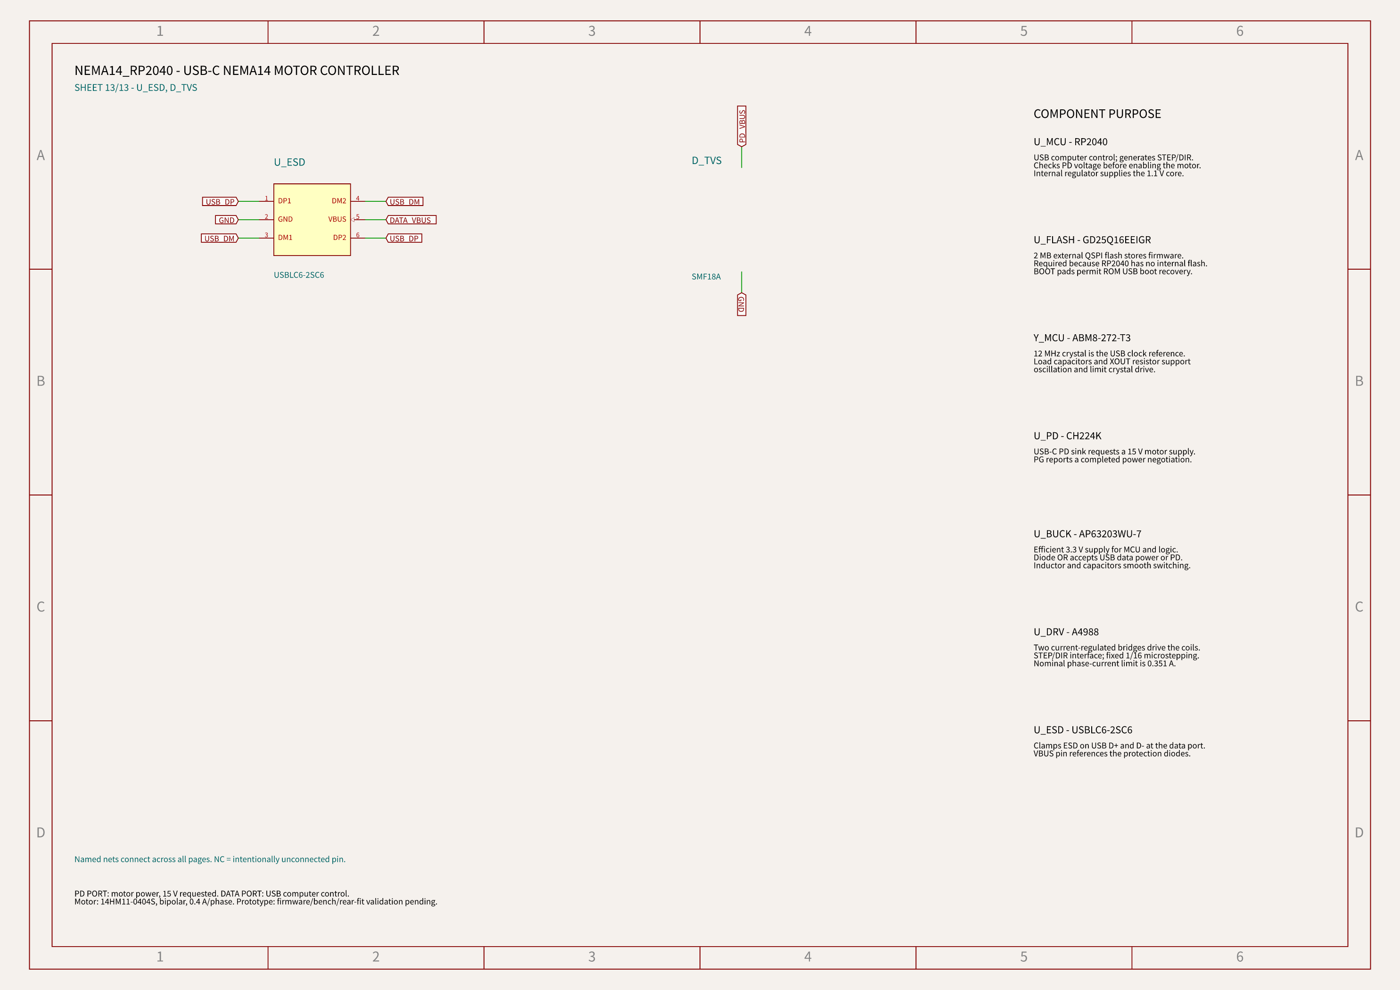
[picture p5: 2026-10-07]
artifacts/schematic-a4-page-13.png

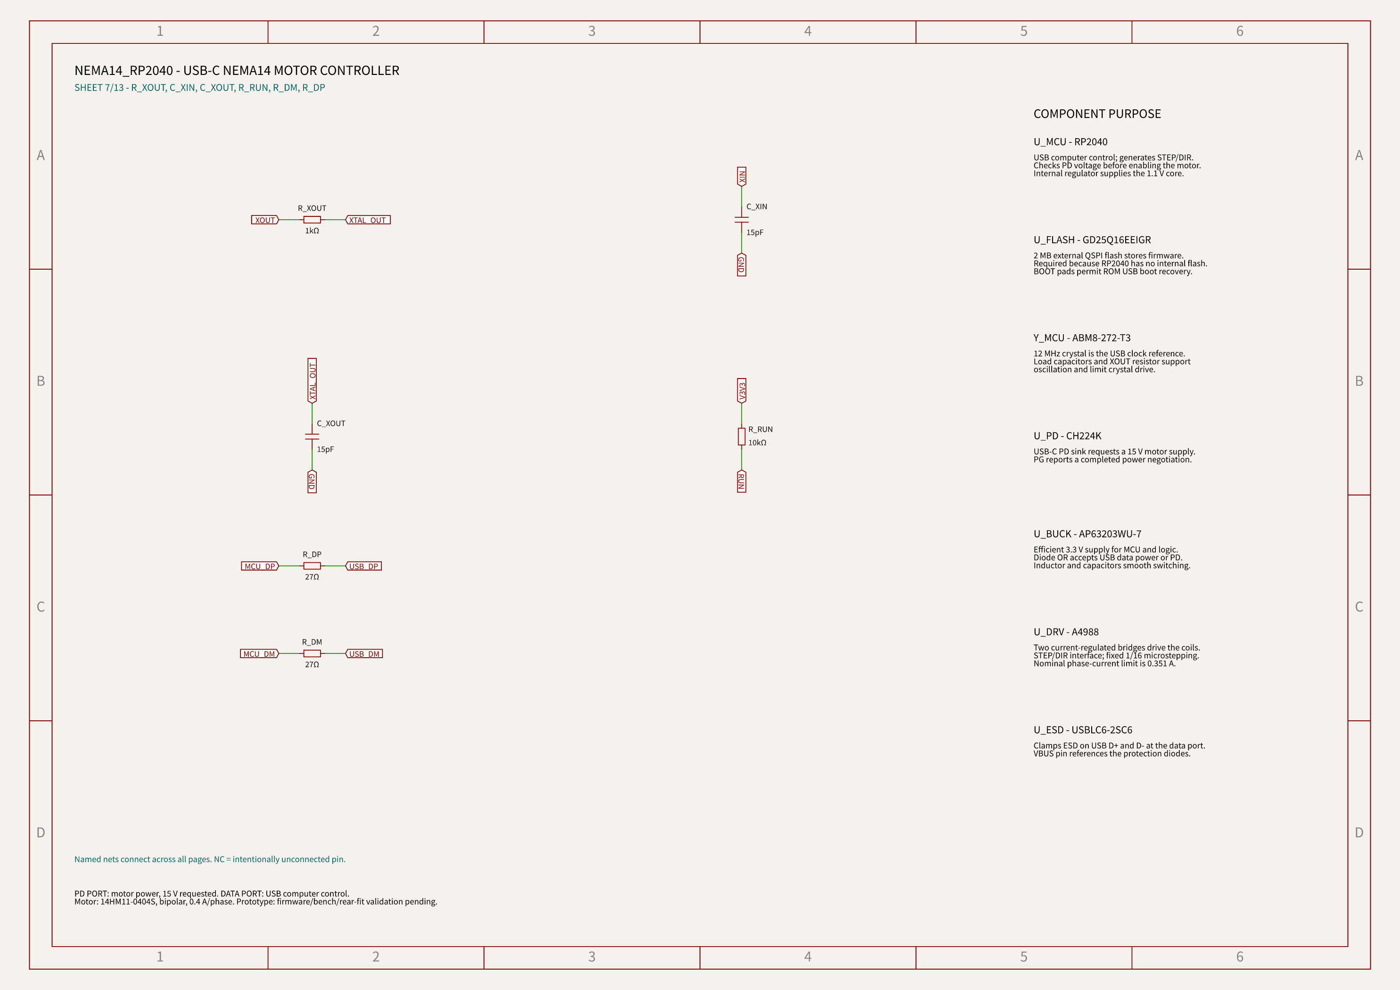
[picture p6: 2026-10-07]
artifacts/schematic-a4-page-07.png

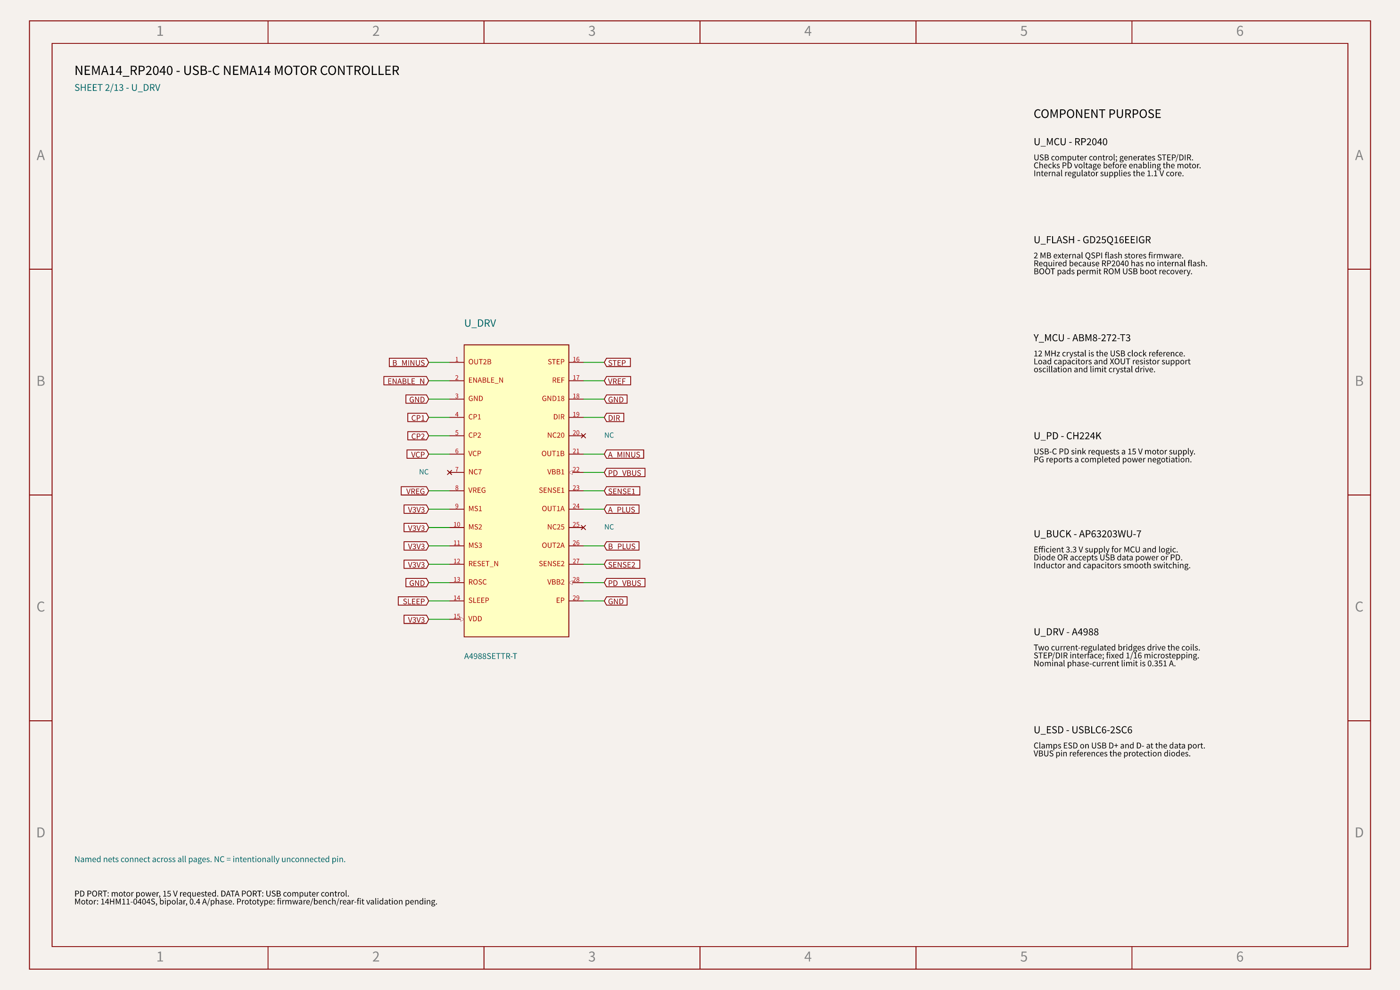
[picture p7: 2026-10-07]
artifacts/schematic-a4-page-02.png

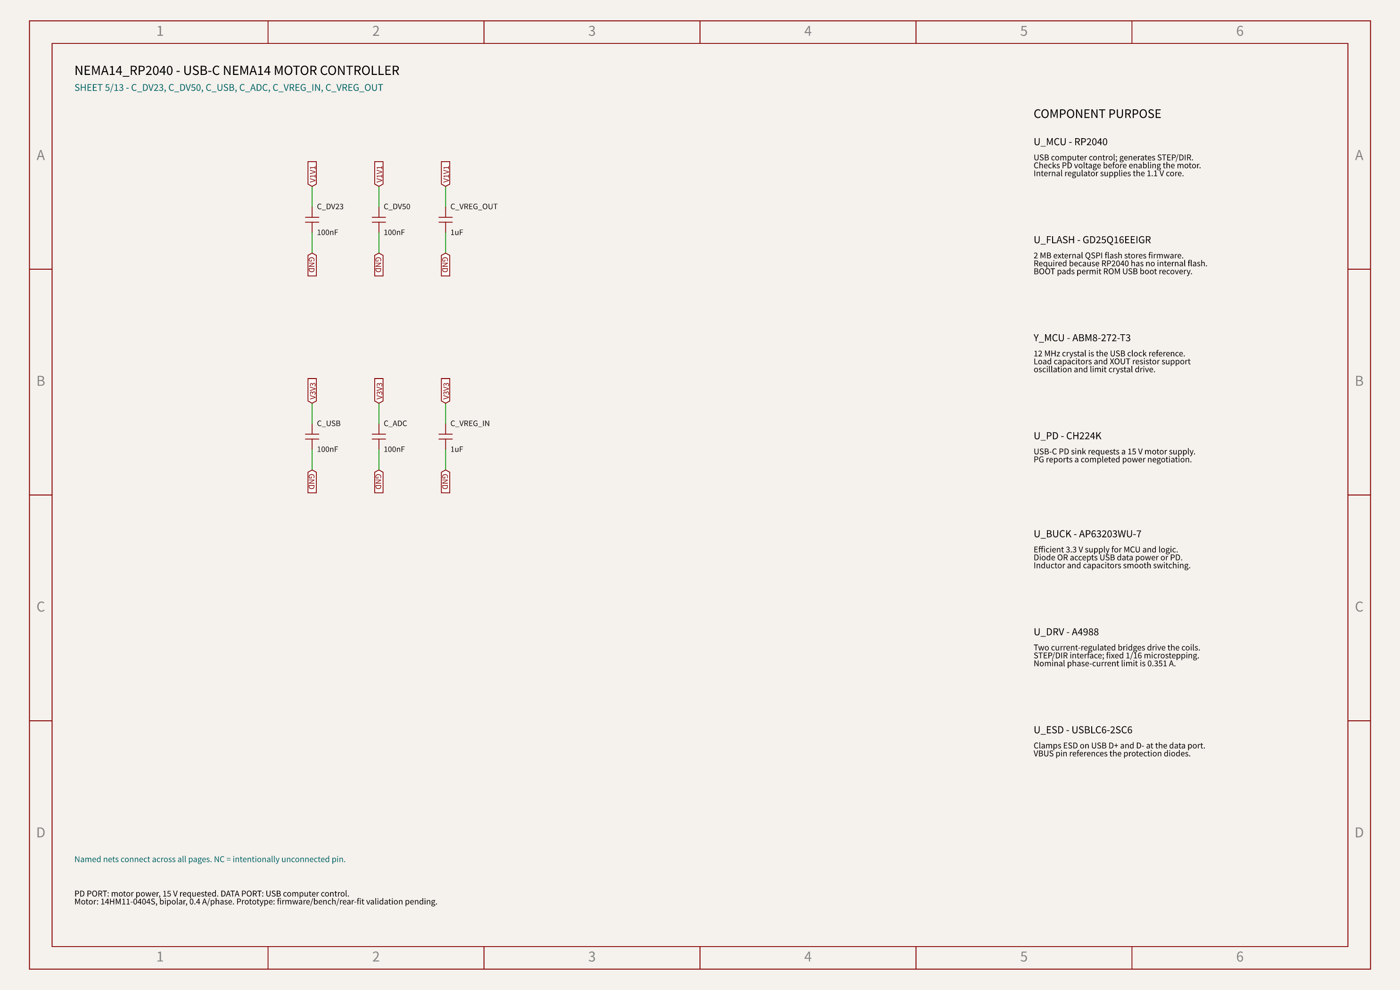
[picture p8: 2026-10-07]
artifacts/schematic-a4-page-05.png

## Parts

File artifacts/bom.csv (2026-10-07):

Reference | MPN | JLCPCB part | Value | Voltage rating (V) | Tolerance | PCB X mm | PCB Y mm | Rotation deg | Assembly side | Review note
J_PD | TYPE-C-31-M-12 | C165948 |  |  |  | -12.57501465 | 4.5 | 270 | top | native supplier import with OBJ and STEP
J_DATA | TYPE-C-31-M-12 | C165948 |  |  |  | 12.57501465 | 4.5 | 90 | top | native supplier import with OBJ and STEP
U_PD | CH224K | C970725 |  |  |  | -3.4000000000000004 | 8.2 | 270 | top | native supplier import with OBJ and STEP
R_PD | ERJPA3F1001V | C441922 | 1kΩ |  |  | -8.5 | 11.7 | 0 | top | native supplier import with OBJ and STEP
C_PD | CL10A105KB8NNNC | C15849 | 1uF | 10 |  | -5.5 | 11.7 | 0 | top | native supplier import with OBJ and STEP
R_PG | 0603WAF1002T5E | C25804 | 10kΩ |  |  | -0.5 | 11.8 | 0 | top | native supplier import with OBJ and STEP
U_MCU | RP2040 | C2040 |  |  |  | 3.4 | 0 | 0 | top | native supplier import with OBJ and STEP
C_IO1 | CL05B104KO5NNNC | C1525 | 100nF | 10 |  | -0.3 | 4.8 | 180 | top | native supplier import with OBJ and STEP
C_IO10 | CL05B104KO5NNNC | C1525 | 100nF | 10 |  | -4.1 | -1.2 | 90 | top | native supplier import with OBJ and STEP
C_IO22 | CL05B104KO5NNNC | C1525 | 100nF | 10 |  | 4 | -5.4 | 270 | top | native supplier import with OBJ and STEP
C_IO33 | CL05B104KO5NNNC | C1525 | 100nF | 10 |  | 8.25 | -1.2 | 90 | top | native supplier import with OBJ and STEP
C_IO42 | CL05B104KO5NNNC | C1525 | 100nF | 10 |  | 8.25 | 2.6 | 90 | top | native supplier import with OBJ and STEP
C_IO49 | CL05B104KO5NNNC | C1525 | 100nF | 10 |  | 3.5 | 5.3 | 90 | top | native supplier import with OBJ and STEP
C_DV23 | CL05B104KO5NNNC | C1525 | 100nF | 10 |  | 5.2 | -5.4 | 90 | top | native supplier import with OBJ and STEP
C_DV50 | CL05B104KO5NNNC | C1525 | 100nF | 10 |  | 2.4 | 5.3 | 90 | top | native supplier import with OBJ and STEP
C_USB | CL05B104KO5NNNC | C1525 | 100nF | 10 |  | 4.3 | 7.4 | 90 | top | native supplier import with OBJ and STEP
C_ADC | CL05B104KO5NNNC | C1525 | 100nF | 10 |  | 7.1 | 5.3 | 90 | top | native supplier import with OBJ and STEP
C_VREG_IN | CL05A105KA5NQNC | C52923 | 1uF | 10 |  | 6.5 | 7.4 | 90 | top | native supplier import with OBJ and STEP
C_VREG_OUT | CL05A105KA5NQNC | C52923 | 1uF | 10 |  | 5.4 | 7.4 | 90 | top | native supplier import with OBJ and STEP
U_FLASH | GD25Q16EEIGR | C2986331 |  |  |  | 2 | 8.6 | 0 | top | native supplier import with OBJ and STEP
C_FLASH | CL05B104KO5NNNC | C1525 | 100nF | 10 |  | 2 | 11.4 | 0 | top | native supplier import with OBJ and STEP
R_FLASH_CS | 0402WGF1002TCE | C25744 | 10kΩ |  |  | 2 | 12.6 | 0 | top | native supplier import with OBJ and STEP
R_BOOT | 0402WGF1001TCE | C11702 | 1kΩ |  |  | 5.5 | 12.9 | 0 | top | native supplier import with OBJ and STEP
J_BOOT |  |  |  |  |  | 8.2 | 15.5 | 0 | top | bare PCB interface
Y_MCU | ABM8-272-T3 | C20625731 |  |  |  | 1.0999999999999999 | -6.16 | 0 | top | native supplier import with OBJ and STEP
R_XOUT | 0402WGF1001TCE | C11702 | 1kΩ |  |  | 4.3 | -7 | 0 | top | native supplier import with OBJ and STEP
C_XIN | 0402CG150J500NT | C1548 | 15pF | 10 |  | -1.55 | -7 | 90 | top | native supplier import with OBJ and STEP
C_XOUT | 0402CG150J500NT | C1548 | 15pF | 10 |  | 5.5 | -8.5 | 90 | top | native supplier import with OBJ and STEP
R_RUN | 0402WGF1002TCE | C25744 | 10kΩ |  |  | 6.9 | -5.5 | 90 | top | native supplier import with OBJ and STEP
R_DM | 0402WGF270JTCE | C25100 | 27Ω |  |  | 5.9 | 5.3 | 90 | top | native supplier import with OBJ and STEP
R_DP | 0402WGF270JTCE | C25100 | 27Ω |  |  | 4.7 | 5.3 | 90 | top | native supplier import with OBJ and STEP
R_CC1 | 0603WAF5101T5E | C23186 | 5.1kΩ |  |  | 8.8 | 12 | 0 | top | native supplier import with OBJ and STEP
R_CC2 | 0402WGF5101TCE | C25905 | 5.1kΩ |  |  | 13 | 16.4 | 0 | top | native supplier import with OBJ and STEP
R_USB_SENSE_H | 0603WAF1003T5E | C25803 | 100kΩ |  |  | 4.7 | 15.7 | 0 | top | native supplier import with OBJ and STEP
R_USB_SENSE_L | 0603WAF1003T5E | C25803 | 100kΩ |  |  | 14.7 | -1.65 | 0 | top | native supplier import with OBJ and STEP
R_VM_H | 0603WAF1003T5E | C25803 | 100kΩ |  |  | -0.5 | 14 | 0 | top | native supplier import with OBJ and STEP
R_VM_L | 0603WAF1002T5E | C25804 | 10kΩ |  |  | 3 | 14.1 | 0 | top | native supplier import with OBJ and STEP
C_VM_SENSE | CL05B103KB5NNNC | C15195 | 10nF | 10 |  | 12 | -3.8 | 0 | top | native supplier import with OBJ and STEP
U_BUCK | AP63203WU-7 | C780769 |  |  |  | -6.6 | -2.8500000000000005 | 180 | top | native supplier import with OBJ and STEP
L_BUCK | SRN4018-4R7M | C780206 | 4.7µH |  |  | -6 | -7.25 | 0 | top | native supplier import with OBJ and STEP
C_BOOTSTRAP | CL05B104KO5NNNC | C1525 | 100nF | 35 |  | -4.2 | -3.3 | 90 | top | native supplier import with OBJ and STEP
C_BUCK_IN | CL31A106KBHNNNE | C13585 | 10uF | 35 |  | -7.799999999999999 | 1.9 | 90 | top | native supplier import with OBJ and STEP
C_BUCK_OUT1 | CL21A226MAQNNNE | C45783 | 22uF | 10 |  | -6.4 | -10.6 | 0 | top | native supplier import with OBJ and STEP
C_BUCK_OUT2 | CL21A226MAQNNNE | C45783 | 22uF | 10 |  | -8 | -12.7 | 0 | top | native supplier import with OBJ and STEP
D_PD | B5819W SL | C8598 |  |  |  | -4 | 3.8 | 0 | top | native supplier import with OBJ and STEP
D_DATA | B5819W SL | C8598 |  |  |  | -4 | 1 | 0 | top | native supplier import with OBJ and STEP
U_DRV | A4988SETTR-T | C38437 |  |  |  | 0.00010000000000021103 | -11.5001 | 270 | top | native supplier import with OBJ and STEP
C_CP | CC0603KRX7R9BB104 | C14663 | 100nF | 35 |  | -4.6 | -12.3 | 0 | top | native supplier import with OBJ and STEP
C_VCP | CC0603KRX7R9BB104 | C14663 | 100nF | 35 |  | -7.1 | -16.5 | 0 | top | native supplier import with OBJ and STEP
C_VREG | CL10B224KA8NNNC | C21120 | 220nF | 10 |  | -5 | -14.8 | 90 | top | native supplier import with OBJ and STEP
C_DRV_LOGIC | CC0603KRX7R9BB104 | C14663 | 100nF | 10 |  | 4.9 | -10.2 | 0 | top | native supplier import with OBJ and STEP
C_VM | CC0805KRX7R9BB104 | C49678 | 100nF | 35 |  | -2.6 | -3.8999999999999995 | 90 | top | native supplier import with OBJ and STEP
C_BULK | RVT1V470M0605 | C72522 | 47uF | 35 |  | -12.05 | -5.4 | 90 | top | native supplier import with OBJ and STEP
R_SA | FRL0805FR240TS | C2930216 | 240mΩ |  |  | 6.8 | -12.8 | 90 | top | native supplier import with OBJ and STEP
R_SB | FRL0805FR240TS | C2930216 | 240mΩ |  |  | -8 | -14.7 | 0 | top | native supplier import with OBJ and STEP
R_REF_H | 0603WAF3902T5E | C23153 | 39kΩ |  |  | 10.9 | -5.5 | 0 | top | native supplier import with OBJ and STEP
R_REF_L | 0603WAF1002T5E | C25804 | 10kΩ |  |  | 11.5 | -8.2 | 0 | top | native supplier import with OBJ and STEP
C_REF | CL10B103KB8NNNC | C1589 | 10nF | 10 |  | 8.7 | -10 | 0 | top | native supplier import with OBJ and STEP
R_ENABLE | 0402WGF1003TCE | C25741 | 100kΩ |  |  | -1.9 | -0.7 | 180 | top | native supplier import with OBJ and STEP
R_SLEEP | 0603WAF1003T5E | C25803 | 100kΩ |  |  | -6 | 13.5 | 0 | top | native supplier import with OBJ and STEP
J_MOTOR |  |  |  |  |  | 0 | -16 | 0 | top | bare PCB interface
J_DEBUG |  |  |  |  |  | 15.5 | -6.3 | 90 | top | bare PCB interface
U_ESD | USBLC6-2SC6 | C2687116 |  |  |  | 5.3 | 10.5 | 270 | top | native supplier import with OBJ and STEP
D_TVS | SMF18A | C19077512 |  |  |  | -7 | 15.6 | 180 | top | native supplier import with OBJ and STEP

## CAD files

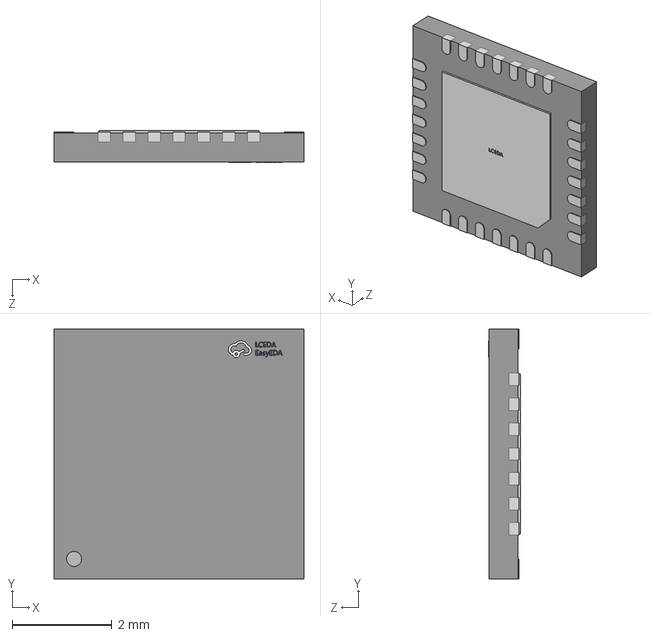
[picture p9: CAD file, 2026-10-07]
imports/supplier/A4988SETTR_T/A4988SETTR_T.step
5.00 x 5.00 x 0.631 mm

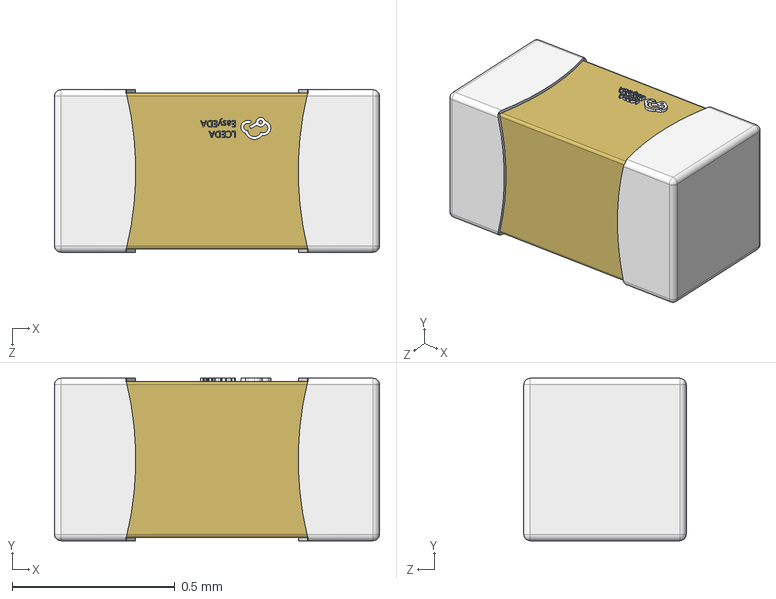
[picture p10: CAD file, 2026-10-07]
imports/supplier/A_0402CG150J500NT/A_0402CG150J500NT.step
1.00 x 0.5 x 0.5 mm

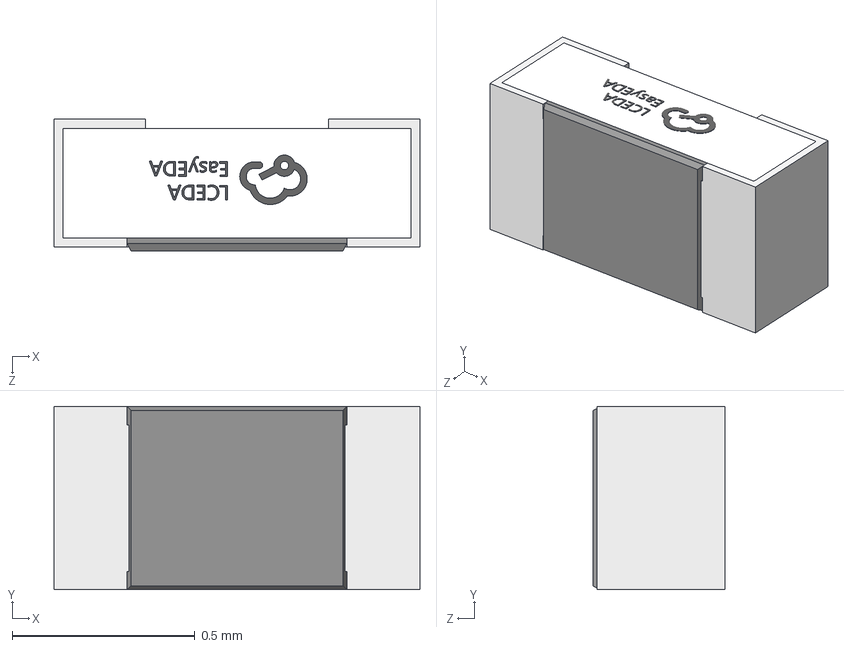
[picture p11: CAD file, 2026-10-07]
imports/supplier/A_0402WGF1001TCE/A_0402WGF1001TCE.step
1.00 x 0.501 x 0.36 mm

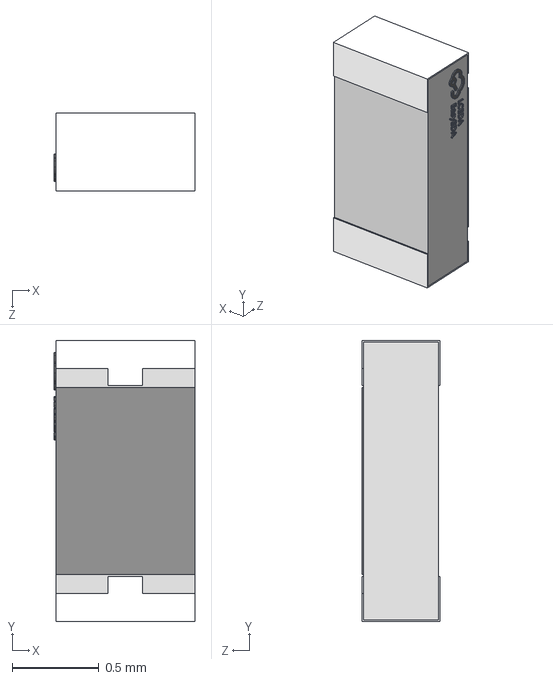
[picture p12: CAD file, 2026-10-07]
imports/supplier/A_0603WAF1001T5E/A_0603WAF1001T5E.step
0.81 x 1.62 x 0.45 mm

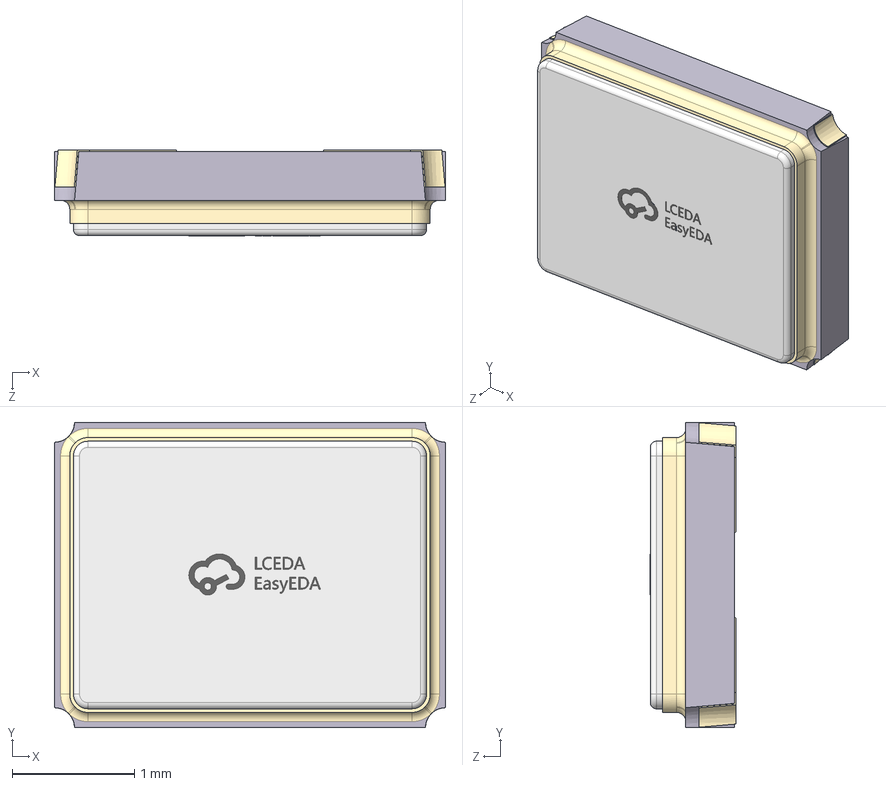
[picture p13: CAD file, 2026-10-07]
imports/supplier/ABM8_272_T3/ABM8_272_T3.step
3.20 x 2.50 x 0.701 mm

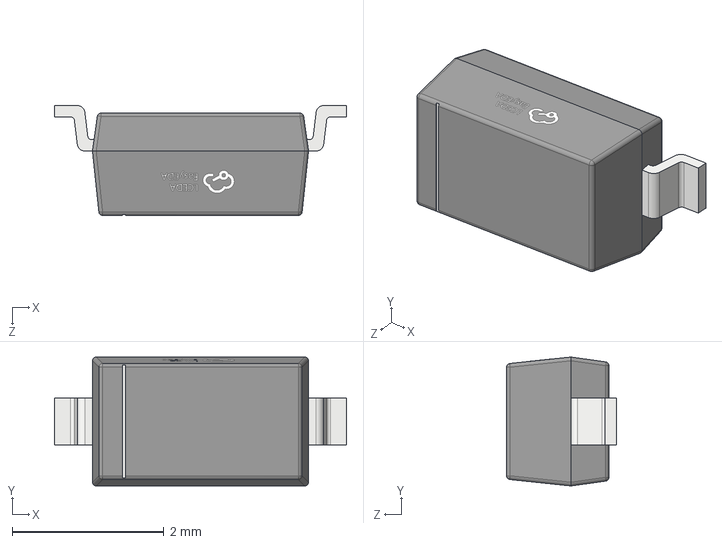
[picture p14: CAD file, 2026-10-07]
imports/supplier/B5819W_SL/B5819W_SL.step
3.85 x 1.70 x 1.45 mm

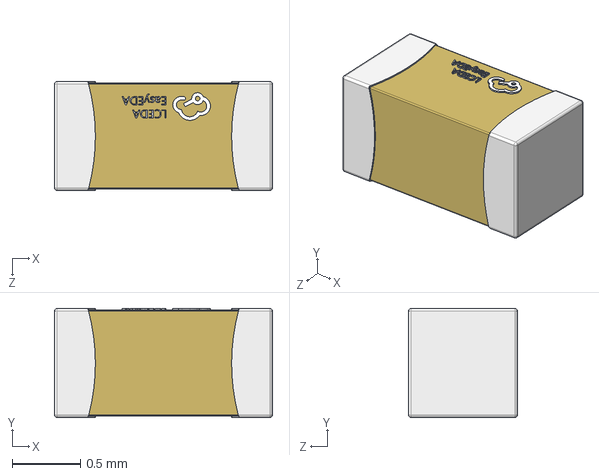
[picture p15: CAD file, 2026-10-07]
imports/supplier/CC0603KRX7R9BB104/CC0603KRX7R9BB104.step
1.60 x 0.8 x 0.8 mm

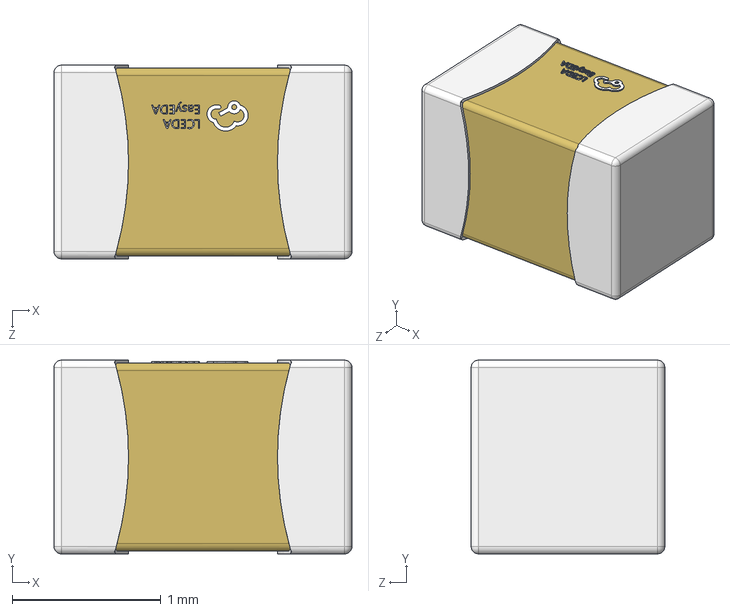
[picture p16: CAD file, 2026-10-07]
imports/supplier/CC0805KRX7R9BB104/CC0805KRX7R9BB104.step
2.00 x 1.30 x 1.30 mm

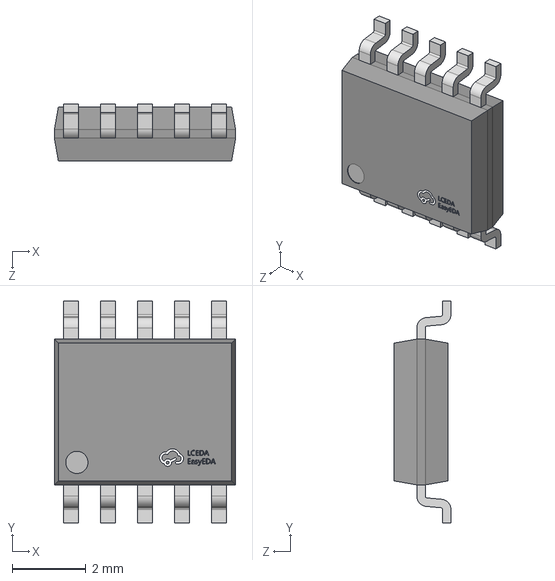
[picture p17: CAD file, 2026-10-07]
imports/supplier/CH224K/CH224K.step
4.90 x 6.00 x 1.54 mm

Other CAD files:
imports/supplier/A4988SETTR_T/A4988SETTR_T.obj
imports/supplier/ABM8_272_T3/ABM8_272_T3.obj
imports/supplier/AP63203WU_7/AP63203WU_7.obj
imports/supplier/AP63203WU_7/AP63203WU_7.step
imports/supplier/A_0402CG150J500NT/A_0402CG150J500NT.obj
imports/supplier/A_0402WGF1001TCE/A_0402WGF1001TCE.obj
imports/supplier/A_0402WGF1002TCE/A_0402WGF1002TCE.obj
imports/supplier/A_0402WGF1003TCE/A_0402WGF1003TCE.obj
imports/supplier/A_0402WGF270JTCE/A_0402WGF270JTCE.obj
imports/supplier/A_0402WGF5101TCE/A_0402WGF5101TCE.obj
imports/supplier/A_0603WAF1001T5E/A_0603WAF1001T5E.obj
imports/supplier/A_0603WAF1002T5E/A_0603WAF1002T5E.obj
imports/supplier/A_0603WAF1003T5E/A_0603WAF1003T5E.obj
imports/supplier/A_0603WAF2202T5E/A_0603WAF2202T5E.obj
imports/supplier/A_0603WAF3902T5E/A_0603WAF3902T5E.obj
imports/supplier/A_0603WAF5101T5E/A_0603WAF5101T5E.obj
imports/supplier/B5819W_SL/B5819W_SL.obj
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

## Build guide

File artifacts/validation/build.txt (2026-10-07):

> NEMA14_RP2040@1.0.8 check
> bun scripts/check.ts

{
  "traceCount": 519,
  "currentLimitAmps": 0.350765306122449,
  "errors": 0,
  "warnings": 0
}

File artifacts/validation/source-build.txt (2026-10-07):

> NEMA14_RP2040@1.0.8 source:check
> bun scripts/build.tsx --unrouted

Rendering NEMA14 RP2040 with tscircuit local autorouter…
{
  "elements": 3319,
  "traces": 0,
  "errors": []
}

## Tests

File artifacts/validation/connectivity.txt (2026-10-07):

{
  "checkedNets": 48,
  "disconnectedNets": [],
  "allCopperLayersChecked": true,
  "nativePolygonAndSlotGeometry": true,
  "sha256": "56fcfb9664f04f9e8acd68431e6955105edf9a25fffab272244bb554e8e80c2b"
}

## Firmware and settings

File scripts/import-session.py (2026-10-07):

"""Import freerouting's SES with its declared units; preserve actual pad geometry."""
import json,pathlib,re,math,sys
ROOT=pathlib.Path(__file__).resolve().parents[1]
prefix=sys.argv[1] if len(sys.argv)>1 else ''
ses=prefix+'-board.ses' if prefix else 'board.ses'
mapfile=prefix+'-map.json' if prefix else 'freerouting-map.json'
outfile=prefix+'.circuit.json' if prefix else 'board.circuit.json'
def parse(s):
 toks=re.findall(r'"(?:\\.|[^"\\])*"|[()]|[^\s()]+',s);stack=[];out=[]
 for t in toks:
  if t=='(': stack.append([])
  elif t==')':
   v=stack.pop()
   (stack[-1] if stack else out).append(v)
  else:stack[-1].append(json.loads(t) if t.startswith('"') else t)
 if stack:raise ValueError('Truncated SES file')
 return out[0]
def children(n,tag):return [c for c in n if isinstance(c,list) and c and c[0]==tag]
s=parse((ROOT/'artifacts'/ses).read_text());routes=children(s,'routes')[0];res=children(routes,'resolution')[0]
assert res[1]=='um';scale=1000*float(res[2])
inputfile=ROOT/'artifacts'/(prefix+'-unrouted.circuit.json')
if not prefix or not inputfile.exists():inputfile=ROOT/'artifacts/unrouted.circuit.json'
j=json.loads(inputfile.read_text())
j=[e for e in j if e['type'] not in ['pcb_trace','pcb_via','pcb_copper_pour'] and not e['type'].endswith('_error')]
meta=json.loads((ROOT/'artifacts'/mapfile).read_text());netids=meta['netids']
sourceports={e['source_port_id']:e for e in j if e['type']=='source_port'};ports={e['pcb_port_id']:e for e in j if e['type']=='pcb_port'}
netkeys={e['name']:e.get('subcircuit_connectivity_map_key') for e in j if e['type']=='source_net'}
for n in set(x['net'] for x in meta['pinmap'].values()):
 if n.startswith('SIGNAL_'):
  k=next(p.get('subcircuit_connectivity_map_key') for p in sourceports.values() if p.get('subcircuit_connectivity_map_key','').endswith('_'+n[7:]));netkeys[n]=k
traceids={}
for e in j:
 if e['type']=='source_trace' :traceids[e.get('subcircuit_connectivity_map_key')]=e['source_trace_id']
pads=[e for e in j if e['type'] in ['pcb_smtpad','pcb_plated_hole']]
def endpoint(x,y,key):
 for p in pads:
  pp=ports.get(p.get('pcb_port_id'),{});sp=sourceports.get(pp.get('source_port_id'),{})
  if sp.get('subcircuit_connectivity_map_key')!=key:continue
  w=p.get('width',p.get('outer_width',p.get('outer_diameter',p.get('radius',0)*2)));h=p.get('height',p.get('outer_height',p.get('outer_diameter',p.get('radius',0)*2)))
  if abs(p.get('ccw_rotation',0)%180-90)<.01:w,h=h,w
  if abs(x-p['x'])<=w/2+.015 and abs(y-p['y'])<=h/2+.015:return p.get('pcb_port_id')
 return None
count=0;vcount=0
for net in children(children(routes,'network_out')[0],'net'):
 name=net[1];key=netkeys.get(name);netid=netids.get(name)
 if name.startswith('NC_'):continue
 for wire in children(net,'wire'):
  path=children(wire,'path')[0];layer={'F.Cu':'top','In2.Cu':'inner2','B.Cu':'bottom'}[path[1]];width=float(path[2])/scale;coords=list(map(float,path[3:]));assert len(coords)%2==0
  route=[{'route_type':'wire','x':coords[i]/scale,'y':coords[i+1]/scale,'width':width,'layer':layer} for i in range(0,len(coords),2)]
  if len(route)<2:continue
  count+=1;elem={'type':'pcb_trace','pcb_trace_id':f'freerouted_trace_{count}','route':route,'subcircuit_id':'subcircuit_source_group_0'}
  if key:elem['subcircuit_connectivity_map_key']=key
  if netid:elem['source_net_id']=netid
  if key in traceids:elem['source_trace_id']=traceids[key]
  for point,tag in [(route[0],'start_pcb_port_id'),(route[-1],'end_pcb_port_id')]:
   pid=endpoint(point['x'],point['y'],key) if layer=='top' else None
   if pid:point[tag]=pid
  elem['pcb_port_ids']=list({point[k] for point in route for k in ['start_pcb_port_id','end_pcb_port_id'] if k in point})
  j.append(elem)
 for via in children(net,'via'):
  vcount+=1;elem={'type':'pcb_via','pcb_via_id':f'freerouted_via_{vcount}','x':float(via[2])/scale,'y':float(via[3])/scale,'hole_diameter':(.25 if via[1]=='via500' else .3),'outer_diameter':(.5 if via[1]=='via500' else .6),'layers':['top','bottom'],'from_layer':'top','to_layer':'bottom','subcircuit_id':'subcircuit_source_group_0','subcircuit_connectivity_map_key':key}
  if netid:elem['source_net_id']=netid
  if key in traceids:elem['source_trace_id']=traceids[key]
  j.append(elem)
# Make layer transitions explicit at true exposed-pad endpoints. SES stores vias separately.
for t in meta['thermalVias']:
 for e in j:
  if e['type']=='pcb_trace' and e.get('source_net_id')==netids['GND']:
   route=e['route'];pt=route[0]
   if pt['layer']=='bottom' and math.hypot(pt['x']-t['x'],pt['y']-t['y'])<.01:
    pid=endpoint(t['x'],t['y'],netkeys['GND'])
    top={'route_type':'wire','x':t['x'],'y':t['y'],'layer':'top','width':pt['width']}
    if pid:top['start_pcb_port_id']=pid
    e['route']=[top,{'route_type':'via','x':t['x'],'y':t['y'],'from_layer':'top','to_layer':'bottom','via_diameter':(.5 if prefix else .6),'via_hole_diameter':(.25 if prefix else .3)}]+route
# Thermal vias are explicit engineering choices and permitted only inside grounded exposed pads.
for t in meta['thermalVias']:
 if not any(e['type']=='pcb_via' and math.hypot(e['x']-t['x'],e['y']-t['y'])<.01 for e in j):
  vcount+=1;j.append({'type':'pcb_via','pcb_via_id':f'freerouted_via_{vcount}','x':t['x'],'y':t['y'],'hole_diameter':(.25 if prefix else .3),'outer_diameter':(.5 if prefix else .6),'layers':['top','bottom'],'from_layer':'top','to_layer':'bottom','source_net_id':netids['GND'],'subcircuit_id':'subcircuit_source_group_0','subcircuit_connectivity_map_key':netkeys['GND']})
if prefix:
 seeds=json.loads((ROOT/'artifacts'/(prefix+'-seeds.circuit.json')).read_text())
 j.extend(e for e in seeds if e['type'] in ['pcb_trace','pcb_via'])
if prefix in ['fixed4','fixed5','fixed6','fixed7','fixed8']:
 for e in j:
  if e['type']=='pcb_via':e['layers']=['top','inner1','inner2','bottom']
for e in j:
 if e['type']=='pcb_board':e['is_via_in_pad_allowed']=True
(ROOT/'artifacts'/outfile).write_text(json.dumps(j,indent=2)+'\n')
print(f'Imported {count} traces and {vcount} vias. Declared SES scale: {scale:g} units/mm.')

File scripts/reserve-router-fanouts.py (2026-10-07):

"""Open MCU escape corridors and reserve explicit inner QFN fanouts."""
import pathlib,json,math
ROOT=pathlib.Path(__file__).resolve().parents[1];path=ROOT/'artifacts/fixed8-seeds.circuit.json';j=json.loads((ROOT/'artifacts/final-source.circuit.json').read_text())
src={e['source_component_id']:e for e in j if e['type']=='source_component'};sp={e['source_port_id']:e for e in j if e['type']=='source_port'};comp={e['pcb_component_id']:e for e in j if e['type']=='pcb_component'};ports={e['pcb_port_id']:e for e in j if e['type']=='pcb_port'};nets={e['subcircuit_connectivity_map_key']:e for e in j if e['type']=='source_net'};traces={e['subcircuit_connectivity_map_key']:e['source_trace_id'] for e in j if e['type']=='source_trace'}
def port(cname,pname):return next(p for p in ports.values() if src[comp[p['pcb_component_id']]['source_component_id']]['name']==cname and sp[p['source_port_id']]['name']==pname)
for pname,rname,bends in [('USB_DP','R_DP',[(4.4,4.15),(4.48,4.35),(4.48,4.79)]),('USB_DM','R_DM',[(4.8,4.15),(5.4,4.15)])]:
 p=port('U_MCU',pname);target=port(rname,'pin1');k=sp[p['source_port_id']]['subcircuit_connectivity_map_key'];name=nets[k]['name'];route=[{'route_type':'wire','x':x,'y':y,'layer':'top','width':.16} for x,y in [(p['x'],p['y'])]+bends+[(target['x'],target['y'])]]
 route[0]['start_pcb_port_id']=p['pcb_port_id'];route[-1]['end_pcb_port_id']=target['pcb_port_id'];j.append({'type':'pcb_trace','pcb_trace_id':'manual_usb_'+name,'route':route,'source_net_id':nets[k]['source_net_id'],'source_trace_id':traces[k],'subcircuit_connectivity_map_key':k,'subcircuit_id':'subcircuit_source_group_0','pcb_port_ids':[p['pcb_port_id'],target['pcb_port_id']]})
# Lower the shared ADC/VREG 3V3 stub to clear the USB DM approach.
for e in j:
 if e['type']=='pcb_trace' and nets.get(e.get('subcircuit_connectivity_map_key'),{}).get('name')=='V3V3':
  for pt in e['route']:
   if pt.get('layer')=='top' and abs(pt['y']-4.1018)<.0001 and 5.5998<pt['x']<6.0001:pt['y']=3.8
# Connect TESTEN vertically to the MCU exposed ground pad, freeing the clock area.
p=port('U_MCU','TESTEN');target=port('U_MCU','GND');k=sp[p['source_port_id']]['subcircuit_connectivity_map_key'];route=[{'route_type':'wire','x':x,'y':y,'layer':'top','width':.16} for x,y in [(p['x'],p['y']),(p['x'],-1.45),(target['x'],target['y'])]];route[0]['start_pcb_port_id']=p['pcb_port_id'];route[-1]['end_pcb_port_id']=target['pcb_port_id'];j.append({'type':'pcb_trace','pcb_trace_id':'manual_TESTEN_ground','route':route,'source_net_id':nets[k]['source_net_id'],'source_trace_id':traces[k],'subcircuit_connectivity_map_key':k,'subcircuit_id':'subcircuit_source_group_0','pcb_port_ids':[p['pcb_port_id'],target['pcb_port_id']]})
fanouts={('U_MCU','GPIO6'):(.9,.1),('U_MCU','GPIO7'):(1.35,-.6),('U_MCU','GPIO8'):(.9,-1.2),('U_MCU','GPIO9'):(1.35,-1.8),('U_MCU','GPIO10'):(.9,-2.5),('U_MCU','XOUT'):(2.8,-2.6),('U_MCU','IOVDD22'):(3.35,-2),('U_MCU','DVDD23'):(4,-2.6),('U_MCU','SWCLK'):(4.55,-2),('U_MCU','SWDIO'):(5.05,-2.6),('U_MCU','RUN'):(5.5,-2),('U_MCU','QSPI_SD3'):(2.9,2.5),('U_MCU','QSPI_SD0'):(1.55,4.275),('U_MCU','QSPI_SD1'):(.8,2),('U_MCU','QSPI_SCLK'):(2.2,4.275),('U_MCU','DVDD50'):(3.5,2),('U_MCU','VREG_OUT'):(5.2,2.55)}
fanouts.update({('U_MCU','QSPI_SD2'):(1.55,2),('U_MCU','QSPI_SS'):(.8,4.275),('U_MCU','GPIO28'):(5.8,1.8),('U_MCU','GPIO29'):(6.3,2.55),('U_MCU','XIN'):(2.4,-4.275),('U_DRV','OUT1A'):(.5,-8.05),('U_DRV','OUT2A'):(-.5,-8.05),('U_DRV','SENSE1'):(1.55,-8.05),('U_DRV','SENSE2'):(-1.55,-8.05),('U_DRV','STEP'):(3.45,-12.5),('U_DRV','SLEEP'):(2.3,-14.9)})
fanouts.update({('U_DRV','OUT2B'):(-3.45,-10),('U_DRV','ENABLE_N'):(-4,-10.5),('U_DRV','CP1'):(-3.45,-11.5),('U_DRV','CP2'):(-4,-12),('U_DRV','VCP'):(-3.45,-12.5),('U_DRV','VREG'):(-2.4,-14.6),('U_DRV','MS3'):(0,-14.95),('U_DRV','VBB1'):(2.5,-8.3),('U_DRV','VBB2'):(-2.5,-8.3),('U_DRV','REF'):(4,-12),('U_DRV','VDD'):(4,-13),('U_DRV','DIR'):(3.45,-11.2),('U_DRV','OUT1B'):(3.45,-9)})

p=port('U_DRV','ENABLE_N');assert abs(p['x']+2.4)<.001 and abs(p['y']+10.5)<.001
k=sp[p['source_port_id']]['subcircuit_connectivity_map_key'];tid='reserved_fanout_U_DRV_ENABLE_N';x,y=-4,-10.7
rr=[{'route_type':'wire','x':xx,'y':yy,'width':.16,'layer':'top'} for xx,yy in [(p['x'],p['y']),(-2.95,-10.6),(-3.25,-10.625),(-3.4,-10.7),(x,y)]]
rr[0]['start_pcb_port_id']=p['pcb_port_id'];rr.extend([{'route_type':'via','x':x,'y':y,'from_layer':'top','to_layer':'bottom','via_diameter':.5,'via_hole_diameter':.25},{'route_type':'wire','x':x,'y':y,'width':.16,'layer':'bottom'}])
j.append({'type':'pcb_trace','pcb_trace_id':tid,'route':rr,'source_net_id':nets[k]['source_net_id'],'source_trace_id':traces[k],'subcircuit_connectivity_map_key':k,'subcircuit_id':'subcircuit_source_group_0','pcb_port_ids':[p['pcb_port_id']]})
j.append({'type':'pcb_via','pcb_via_id':tid+'_via','x':x,'y':y,'hole_diameter':.25,'outer_diameter':.5,'layers':['top','bottom'],'source_net_id':nets[k]['source_net_id'],'subcircuit_connectivity_map_key':k,'subcircuit_id':'subcircuit_source_group_0'})
predefined={'connection':'U_DRV.ENABLE_N','net':'ENABLE_N','via':[x,y],'route':rr}
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

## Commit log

2026-10-07 Create separate RP2040 NEMA14 controller prototype
    [fixed-input.dsn, fixed2-input.dsn, freerouting-input.dsn]
2026-10-07 Complete RP2040 four-layer routing and publish saved hardware prototype
    [bom.csv, fixed-input.dsn, fixed2-input.dsn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]
2026-10-07 Add verified supplier CAD and annotated A4 schematics
    [ABM8_272_T3.obj, ABM8_272_T3.step, AP63203WU_7.obj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]
2026-10-07 Resolve RP2040 electrical metadata and review A4 schematics
2026-10-07 Use complete JLCPCB imports and route the supplier RP2040 footprints
    [A4988SETTR_T.obj, A4988SETTR_T.step, ABM8_272_T3.obj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]
2026-10-07 Record verification of published board and supplier model assets
2026-10-07 Publish root circuit entry point with checked circuit JSON
2026-10-07 Publish native circuit JSON build output with include-dist
2026-10-07 Review power copper and protect motor voltage sensing
    [bom.csv]
2026-10-07 Record public verification of reviewed board files
2026-10-11 Verify exact NEMA14 mounting and USB clearance with native CAM evidence
2026-10-11 Fit same-edge USB-C ports inside 35mm NEMA14 mounting envelope
2026-10-11 Restore fitted JST PH motor connector and reroute NEMA14 RP2040
2026-10-11 Verify public JST release, actual drills and recovered archive
2026-10-12 Add reference feedback circuits and qualify same-edge RP2040 prototype
2026-10-12 Organize RP2040 schematic into five verified functional sheets
2026-10-12 Record verified public RP2040 v1.6.0 schematics and drills
2026-10-12 Increase resistor edge clearance on every RP2040 board side
2026-10-12 Record verified public RP2040 v1.7.0 resistor clearances
2026-10-13 Validate order paste schema and disclose inherited CAD metadata findings
2026-10-13 Include all USB shell and JST joints in assembly review plan
2026-10-13 Publish top-side NEMA14 assembly with standard USB-C and reference JST-SH
2026-10-13 Eliminate native USB schematic label collisions and tighten publication checks
2026-10-13 Record verified public v1.8.2 CAD and JLCPCB review files
2026-10-16 Migrate PD controller to CH224A with fixed 15 V request
2026-10-16 Confirm CH224A VBUS rating and prepare verified prototype publication
2026-10-17 Record fresh RP2040 DRC, short-circuit and CAM verification
2026-10-17 Record final order review and hold RP2040 assembly release
